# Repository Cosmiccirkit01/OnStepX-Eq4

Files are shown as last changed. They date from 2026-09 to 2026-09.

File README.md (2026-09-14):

# EQ4 to GoTo Mount Conversion using OnStepX

Converting a manual Skywatcher EQ4 equatorial mount into a fully computerized GoTo mount using [OnStepX](https://github.com/hjd1964/OnStepX) firmware on an ESP32 microcontroller.

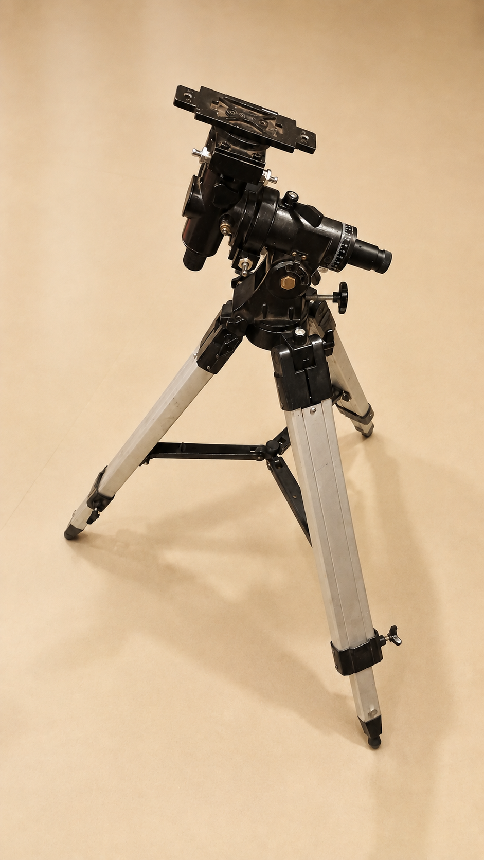
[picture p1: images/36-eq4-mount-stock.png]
Stock EQ4 mount


## Overview

[OnStepX](https://github.com/hjd1964/OnStepX) is an open-source, computerized GoTo controller for telescope mounts, built around stepper motors. It supports both Equatorial and Alt/Az mounts and runs on a range of microcontrollers (ESP32, STM32 Blue Pill/Black Pill, Fysetc boards, Teensy, etc.).

This project documents converting a stock **EQ4 equatorial mount** into a GoTo mount using an **ESP32**, custom-built stepper driver electronics, and a 3D-printed mount for the electronics. It covers everything from flashing the firmware to designing a custom PCB to machining brackets for motors that the mount was never designed to hold.

> **Note:** This is a personal build log, not an official OnStepX guide. Some steps (such as pin assignments and gear ratios) are specific to this hardware combination and may need to be adapted for other mounts or driver boards.

## Table of Contents

- [Bill of Materials](#bill-of-materials)
- [Step 1: Flashing OnStepX Firmware to the ESP32](#step-1-flashing-onstepx-firmware-to-the-esp32)
- [Step 2: Connecting the ESP32 to the OnStep Controller App](#step-2-connecting-the-esp32-to-the-onstep-controller-app)
- [Step 3: Choosing a Motor Driver and Setting Vref](#step-3-choosing-a-motor-driver-and-setting-vref)
- [Step 4: Breadboard Testing](#step-4-breadboard-testing)
- [Step 5: Designing a Custom PCB](#step-5-designing-a-custom-pcb)
- [Step 6: Firmware Configuration](#step-6-firmware-configuration)
- [Step 7: Setting Up the Web Server Plugin](#step-7-setting-up-the-web-server-plugin)
- [Step 8: Servicing the Mount and Fitting Motor Brackets](#step-8-servicing-the-mount-and-fitting-motor-brackets)
- [Safety Notes](#safety-notes)
- [Credits](#credits)
- [Additional Photos & Videos](#additional-photos--videos)
- [Status / Next Steps](#status--next-steps)
- [Note](#Note)

## Bill of Materials

| Component | Notes | Link |
|---|---|---|
| Digital Multimeter | For voltage/continuity checks | [Link](https://robu.in/product/digital-multimeter-small-yellow-color-lcd-ac-dc-measuring-voltage-current/) |
| Breadboard (840 tie points) | For initial circuit testing | [Link](https://robu.in/product/breadboard-840-tie-points-solderless-diy-project-circuit-test-breadboard) |
| ESP32 (ESP-WROOM-32) | Main microcontroller | [Link](https://robu.in/product/esp-wroom-32-esp32-wifi-bt-ble-mcu-module) |
| NEMA17 Stepper Motor | 200 steps/rev, one per axis | [Link](https://robu.in/product/nema17-pr42hs40-1204af-02-4-2kg-cm-stepper-motor-d-type-shaft) |
| DRV8825 Motor Driver | One per axis (see [driver comparison](#step-3-choosing-a-motor-driver-and-setting-vref)) | [Link](https://robu.in/product/drv8825-stepper-motor-driver-with-aluminum-heat-sink) |
| Electrolytic Capacitor (100µF, 50V) | Protects driver from voltage spikes | [Link](https://robu.in/product/100uf-50v-20-chip-type-aluminum-electrolytic-capacitor-smt-pack-of-5) |
| Jumper Cables (M2M) | Breadboard wiring | [Link](https://robu.in/product/male-to-male-jumper-wires-40pcs-20cm) |
| Power Source: 12V, 2A (or 12V, 5A) | 2A is sufficient for testing; upgrade to 5A if needed | [2A](https://robu.in/product/ntl-orange-12vol-2amp-3pin-wall-mount-type-adapter) · [5A](https://robu.in/product/orange-ac-100-240v-to-dc-12v-5a-60w-power-adapter/) |
| Active Buzzer | Status indication | [Link](https://robu.in/product/5v-active-electromagnetic-buzzer-pack-of-5) |
| Step-Down Buck Converter | Steps 12V down to 5V for the driver FLT pin | [Link](https://robu.in/product/mini-360-step-down-buck-converter-power-module) |
| 4-Pin Aviation Connectors | Detachable motor/power connections | [Link](https://robu.in/product/gx-16-4-pin-metal-aviation-plug-male-and-female-panel-connector/) |
| L-shaped brackets (NEMA17) | Mounting motors to the axes | [Link](https://roboticsdna.in/product/bracket-for-nema-17-stepper-motor/) |
| GT2 Pulleys (60T & 12T) | 5:1 gear ratio | [60T](https://robu.in/product/gt2-6mm-belt-width-60-teeth-5mm-bore-aluminium-timing-pulley/) · [12T](https://thinkrobotics.com/products/gt2-timing-pulley?_pos=1&_sid=6cd249838&_ss=r) |
| GT2 Timing Belt | Closed-loop, 180mm | [Link](https://www.superbtech.in/product/180mm-gt2-closed-loop-rubber-timing-belt-6mm-width-for-3d-printer-cnc) |

---

## Step 1: Flashing OnStepX Firmware to the ESP32

1. Download the OnStepX firmware from the [official GitHub repository](https://github.com/hjd1964/OnStepX) — use the **`main`** branch for the latest configuration. Latest version for this build: **10.28**.

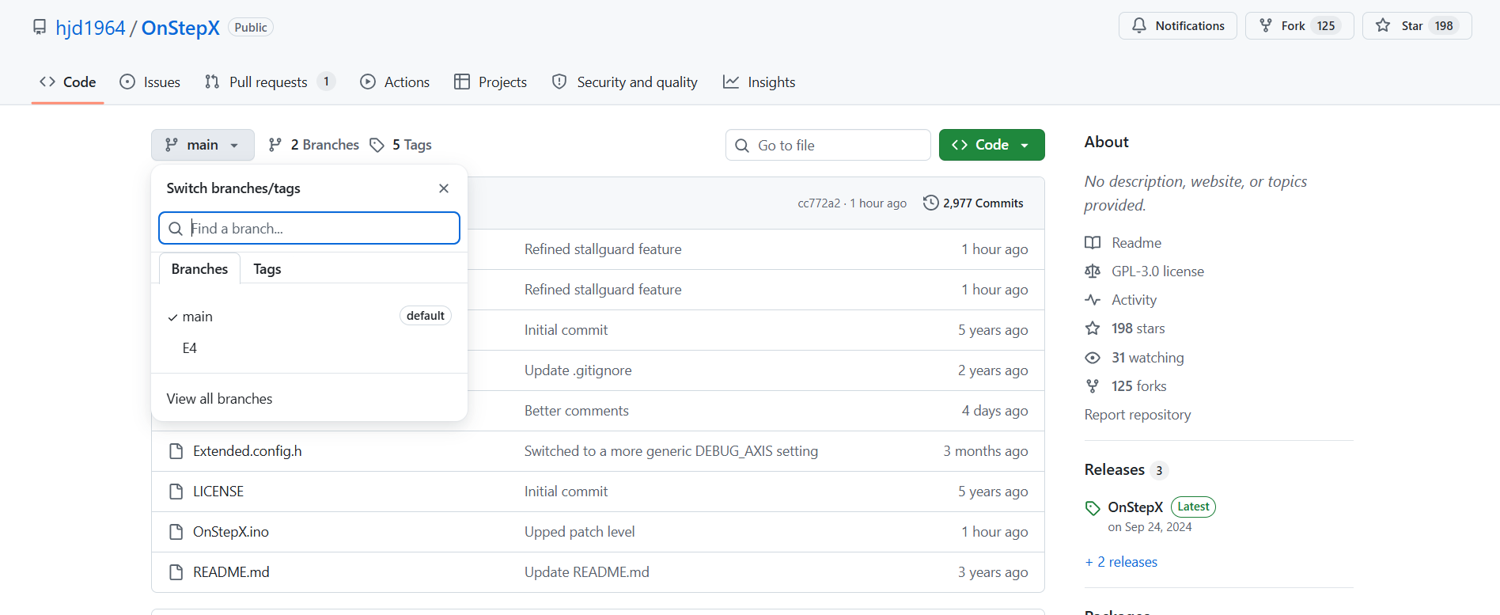
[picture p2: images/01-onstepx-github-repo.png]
OnStepX GitHub repository
   
   *Credits: [hjd1964](https://github.com/hjd1964)*

2. Unzip the downloaded file (it extracts as `OnStepX-main`) and rename the folder to **`OnStepX`**.

3. Open the folder — it should contain the following files:

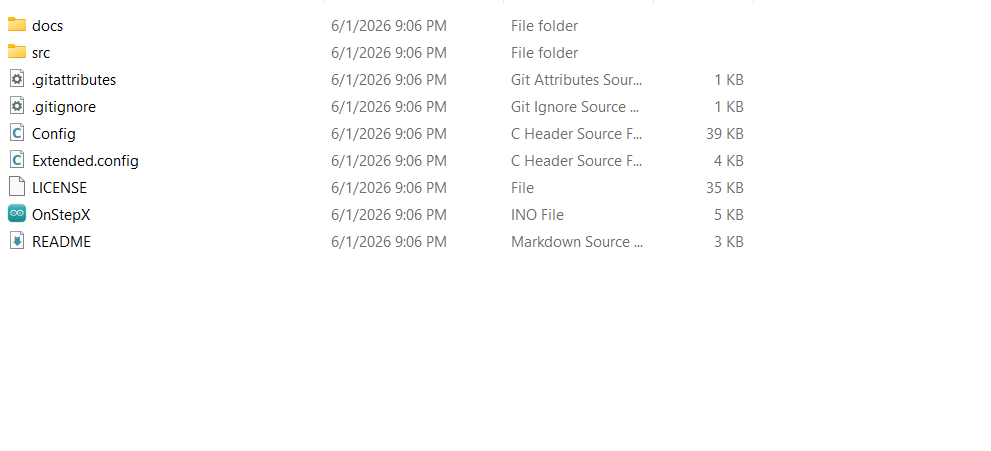
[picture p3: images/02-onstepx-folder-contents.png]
OnStepX folder contents
   

4. Open the **`OnStepX.ino`** file. This launches Arduino IDE along with the `Config.h` and `Extended.config.h` files alongside it.

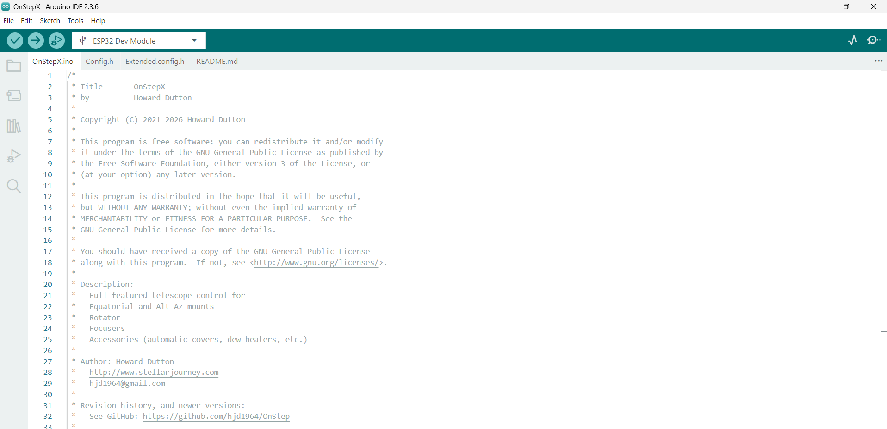
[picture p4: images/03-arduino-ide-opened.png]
Arduino IDE with OnStepX project open
   

   If you don't have Arduino IDE installed, download it from the [official website](https://arduino-ide.org/).

5. **Install the ESP32 USB driver.** The ESP32 dev board uses a CP210x USB-to-UART chip, which needs an external driver on most systems. Follow [this driver installation guide](https://github.com/AnnemHarshaVardhan1811/Install-ESP32-ESP8266-USB-Drivers-CP210x-USB-to-UART-Bridge-Windows-PC-) if needed.

6. **Add the ESP32 board package to Arduino IDE:**
   - Go to **File**

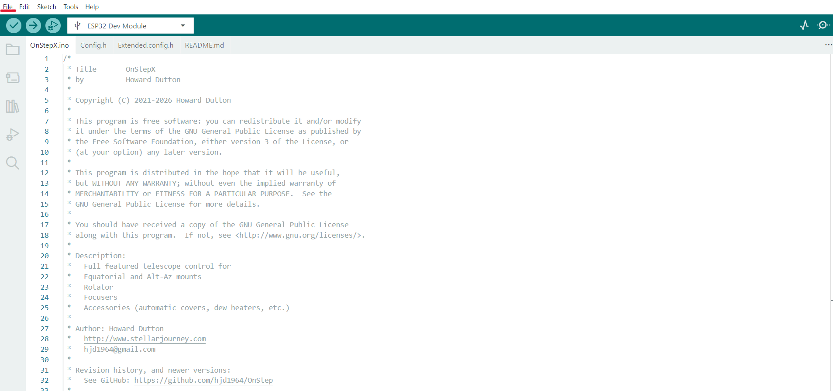
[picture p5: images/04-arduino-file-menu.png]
Arduino IDE File menu
     

   - Go to **Preferences**

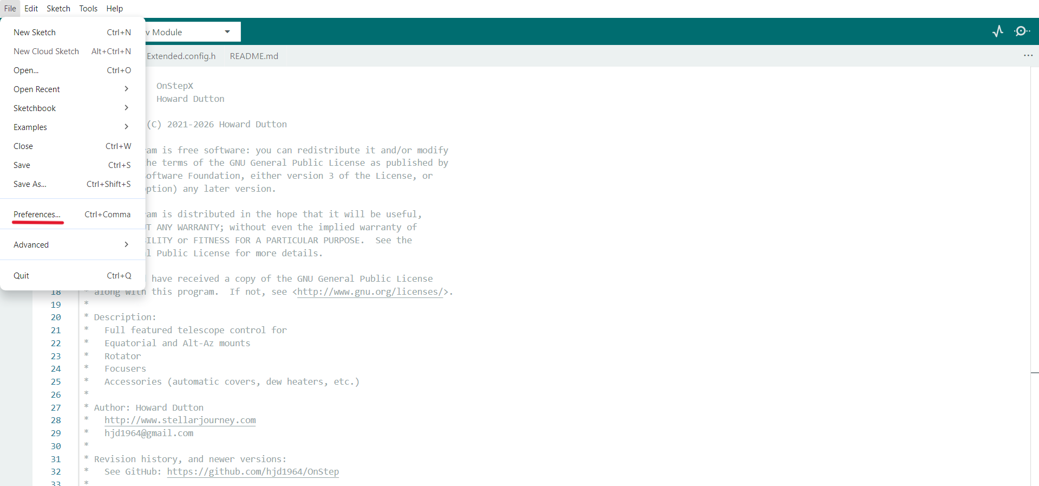
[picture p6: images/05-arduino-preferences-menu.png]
Preferences menu
     

   - In the Preferences window, paste the following URL into **Additional Boards Manager URLs**, then click **OK**:

     ```
     https://raw.githubusercontent.com/espressif/arduino-esp32/gh-pages/package_esp32_index.json
     ```

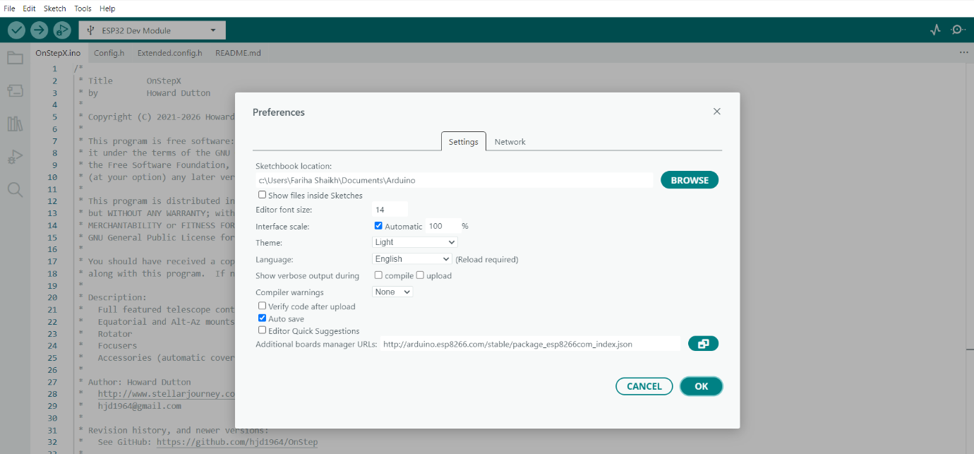
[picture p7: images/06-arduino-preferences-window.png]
Preferences window
     

7. **Select the board and port.** Click the board/port dropdown and choose **"Select other board and port"**.

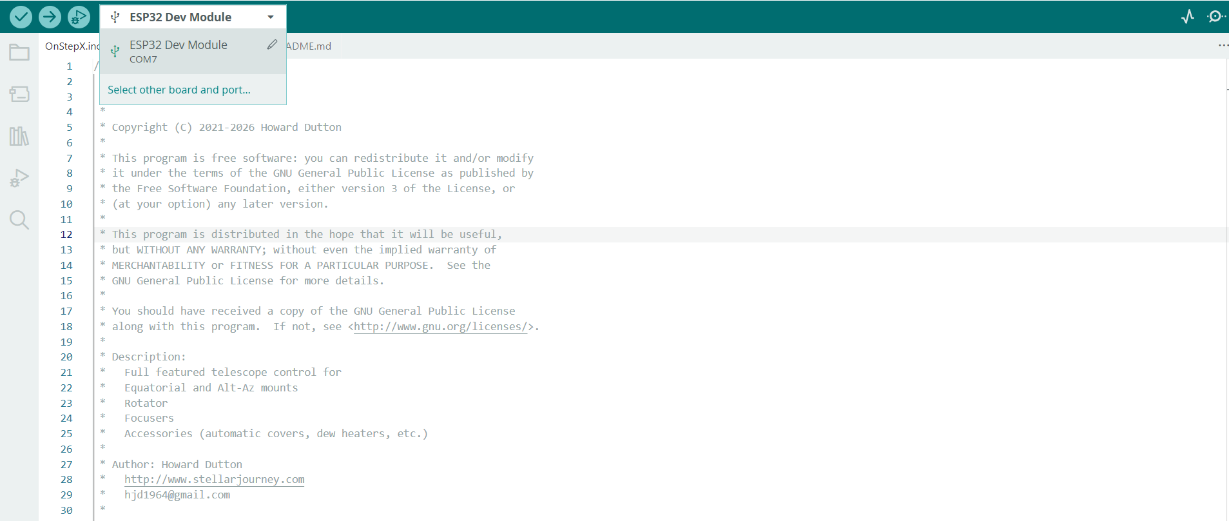
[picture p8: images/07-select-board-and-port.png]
Select board and port
   

   Select your ESP32 variant and the COM port it's connected to (in this build: **ESP32 Dev Module** on **COM7**).

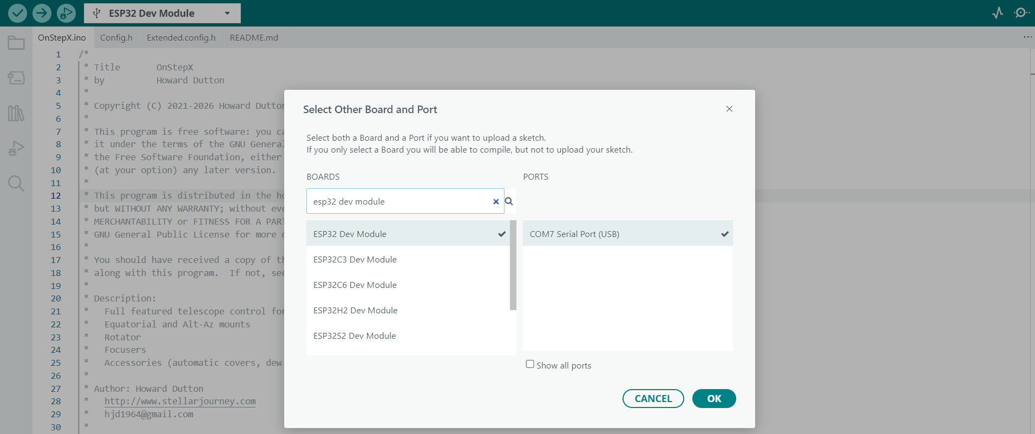
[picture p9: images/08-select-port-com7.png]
Select port COM7
   

8. Click **Upload**.

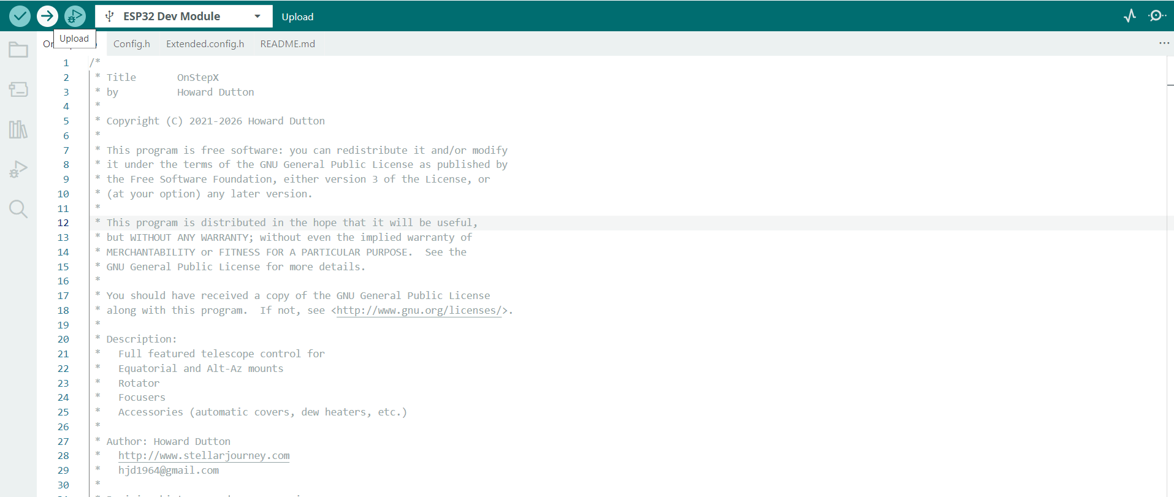
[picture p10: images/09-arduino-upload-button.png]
Upload button
   

9. **Verify the flash succeeded:** open the Serial Monitor, type `#GVP:`, and press Enter. A response of `Onstep` confirms the firmware flashed correctly.

## Step 2: Connecting the ESP32 to the OnStep Controller App

1. Once flashed, the ESP32 broadcasts its own Wi-Fi access point named **`OnStepX`**. Connect to it — the password is **`password`**.

2. Install **OnStep Controller2** from the Play Store and open it.

3. When prompted *"Would you like to create a new one now?"*, tap **Yes**.

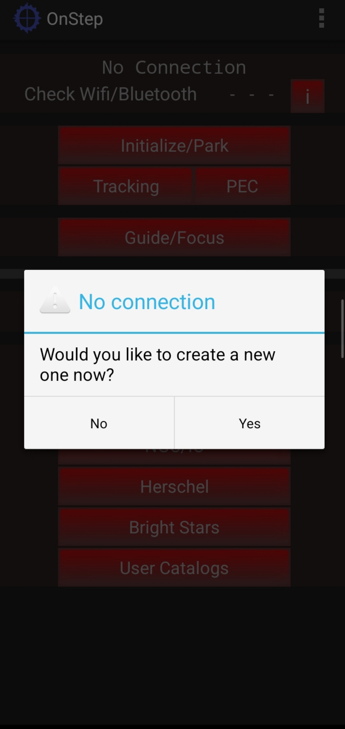
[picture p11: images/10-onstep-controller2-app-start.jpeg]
OnStep Controller2 app start screen
   

4. On the connection screen, enter the IP address **`192.168.0.1`** and tap **Accept**.

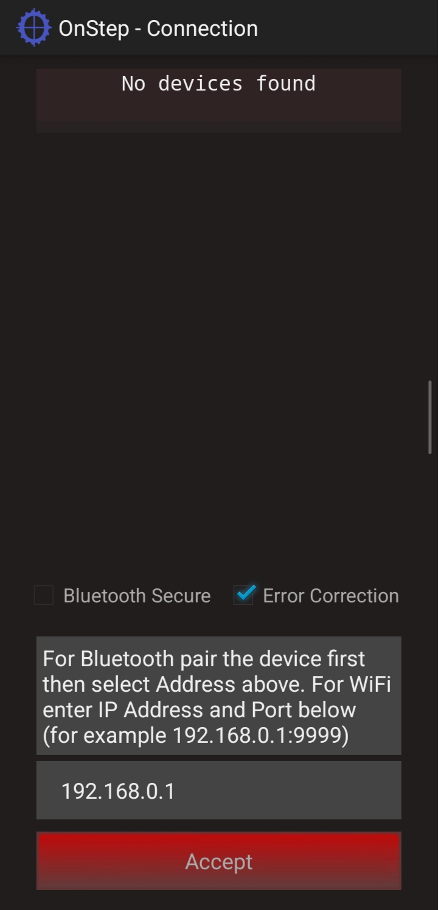
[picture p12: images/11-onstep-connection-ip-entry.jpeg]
Entering the connection IP
   

5. Wait a few seconds for the app to connect to the mount.

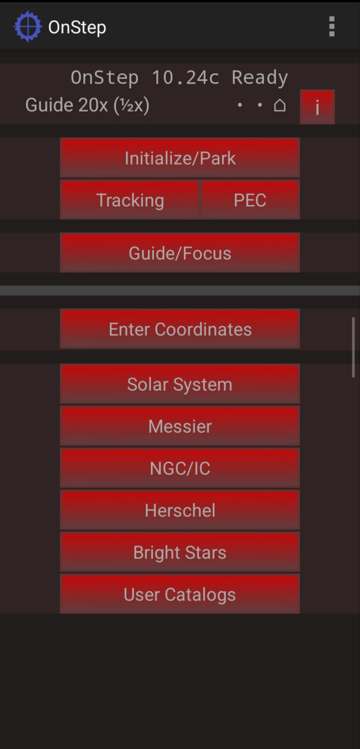
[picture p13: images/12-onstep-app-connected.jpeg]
Connected to the mount
   

6. Tap the **three-dot menu** (top right) → **Observing Sites**, and enter your local **Latitude**, **Longitude**, and **UTC Offset**. Tap **Upload**, then return to the main menu.

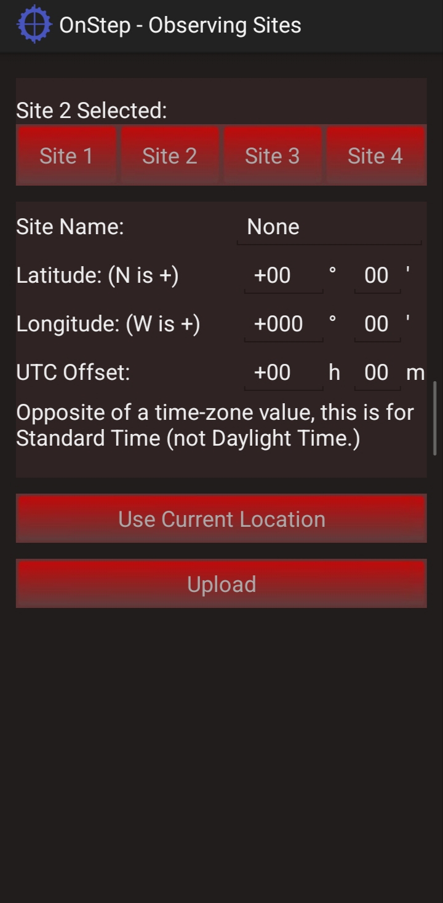
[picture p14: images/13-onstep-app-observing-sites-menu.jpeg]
Observing Sites menu
   

7. From the main menu, go to **Initialize/Park**. This is where most mount actions (park, unpark, home, goto) happen.

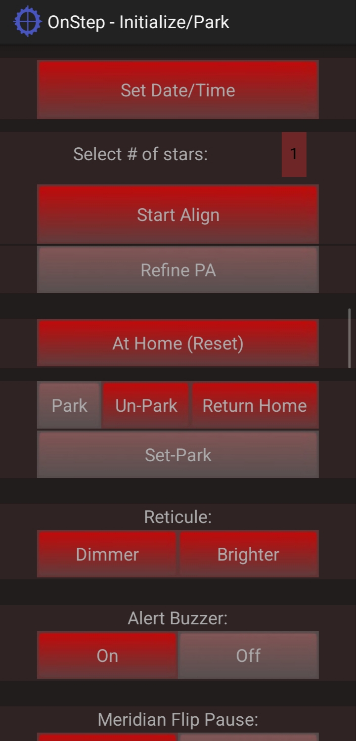
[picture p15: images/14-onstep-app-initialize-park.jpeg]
Initialize/Park screen
   

   > **Important:** Tap **Set Date/Time** before unparking. If this step is skipped, the mount won't accept any further commands.

Alternatively, the [Triton GoTo App](https://tritongoto.com/download) is worth trying — it includes a built-in planetarium view and has a more intuitive setup flow than the stock OnStep app.

## Step 3: Choosing a Motor Driver and Setting Vref

### A4988 vs. DRV8825

A NEMA17 stepper motor takes **200 full steps per revolution** (1.8° per step). Microstepping divides each full step into smaller increments for finer resolution:

| Driver | Max microsteps | Degrees per microstep | Steps per revolution |
|---|---|---|---|
| A4988 | 16 | 1.8° / 16 = 0.1125° | 3,200 |
| DRV8825 | 32 | 1.8° / 32 = 0.05625° | 6,400 |

Finer steps mean smoother, more precise tracking — important for accurately locating objects in the sky. This build started with an A4988 for initial testing, then upgraded to the **DRV8825** for higher resolution (and for a second reason covered in [Step 5](#step-5-designing-a-custom-pcb)).

### Setting the reference voltage (Vref)

Vref limits the current the driver delivers to the motor, protecting both the driver and the motor from damage.

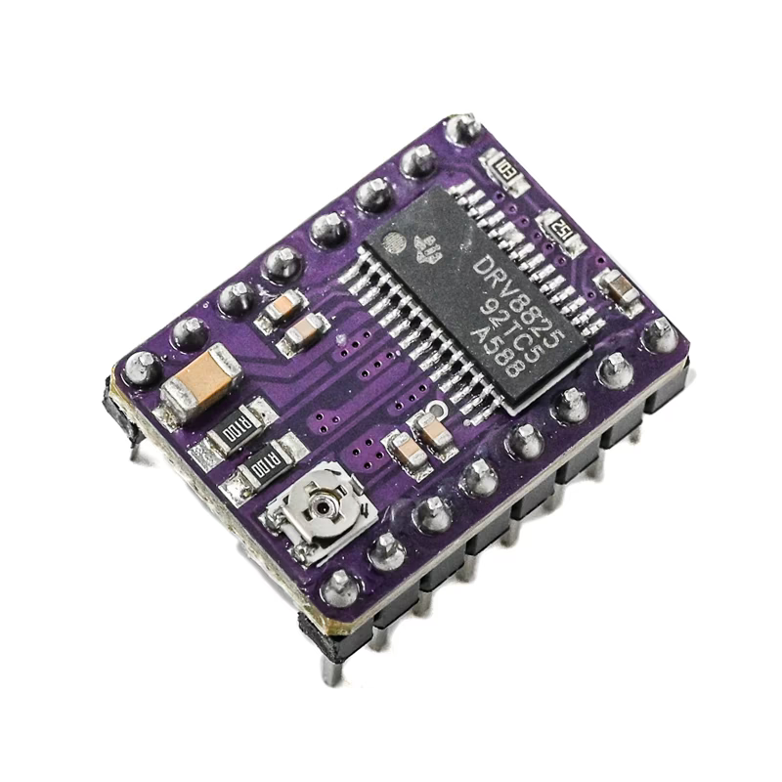
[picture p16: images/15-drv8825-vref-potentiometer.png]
DRV8825 Vref potentiometer


Vref is set using the small potentiometer on the driver board (turn carefully with a small screwdriver — it's easy to damage).

**Formula:**

```
Vref = Imax / 2
```

For the NEMA17 motor used here, `Imax = 1.2A` per phase:

```
Vref = 1.2 / 2 = 0.6V
```

For a safety margin, this build used **10% less**:

```
Vref = 0.5V
```

**To measure and set it:** power the driver with +5V (connect GND to GND, and FLT to +5V — the pinout may differ slightly by board, but this method works regardless). With the multimeter's red probe on the potentiometer and black probe on GND, adjust until the reading matches your target Vref.

If you run into trouble, [this YouTube tutorial](https://youtu.be/wcLeXXATCR4?si=PvDwpPcGoeFdWh77) walks through the process on an A4988 — the same steps apply to the DRV8825. The main difference is that the DRV8825 has a **FLT** pin where the A4988 has **VDD**. See the [DRV8825 connection notes](https://robu-prod-media.s3.ap-south-1.amazonaws.com/uploads/2017/12/Stepper-Motor-Driver-DRV8825-Power-Dissipitation-Considerations.pdf) for reference.

Datasheets: [DRV8825](https://robu-prod-media.s3.ap-south-1.amazonaws.com/uploads/2017/12/drv8825.pdf) · [A4988](https://robu-prod-media.s3.ap-south-1.amazonaws.com/uploads/2015/12/pololu_a4988-1.pdf)

## Step 4: Breadboard Testing

1. **Identify motor coil pairs.** On this motor, Red/Blue was Coil 1 and Green/Black was Coil 2 — verify yours with a multimeter or the tutorial linked above, since wire colors vary by motor.

2. **Find your ESP32 pinmap.** Inside the OnStepX folder, go to:

   ```
   OnStepX > src > pinmaps
   ```

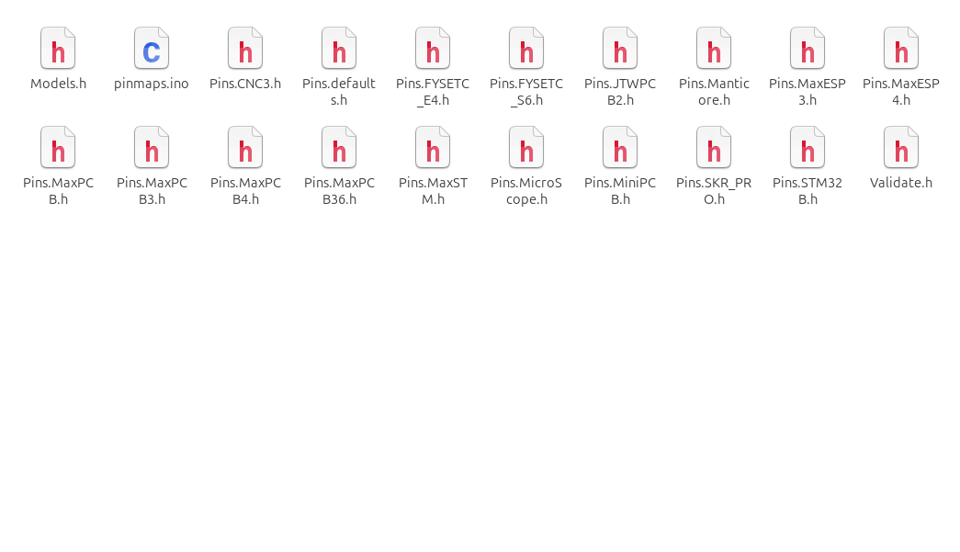
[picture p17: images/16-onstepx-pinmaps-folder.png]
Pinmaps folder
   

   Select the file matching your MCU — this build used **`Pins.MaxESP3.h`**.

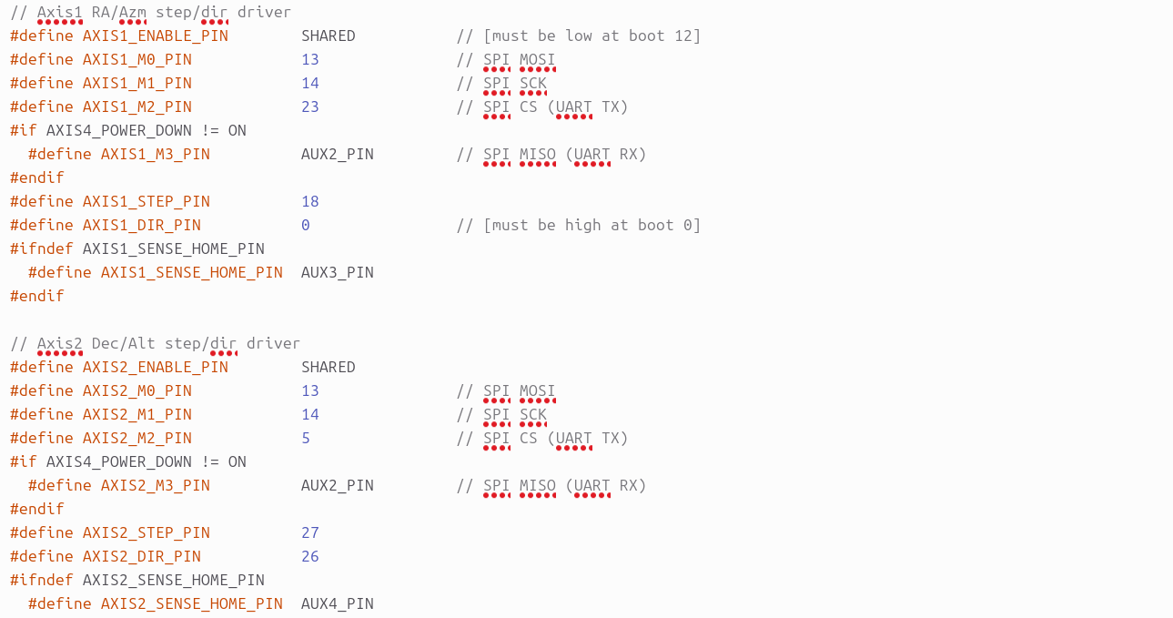
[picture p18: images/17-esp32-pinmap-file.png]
ESP32 pinmap file open
   

   Scroll to the **AXIS1** / **AXIS2** definitions and wire accordingly. Optional buzzer/LED status pins can also be added here.

3. **Wire the power stage.** Connect the 100µF electrolytic capacitor as shown in the [wiring video](https://youtu.be/wcLeXXATCR4?si=PvDwpPcGoeFdWh77) above. `VMOT` connects to **+12V**, and `FLT` connects to **+5V** — ideally from a step-down buck converter rather than the ESP32's own 5V rail.

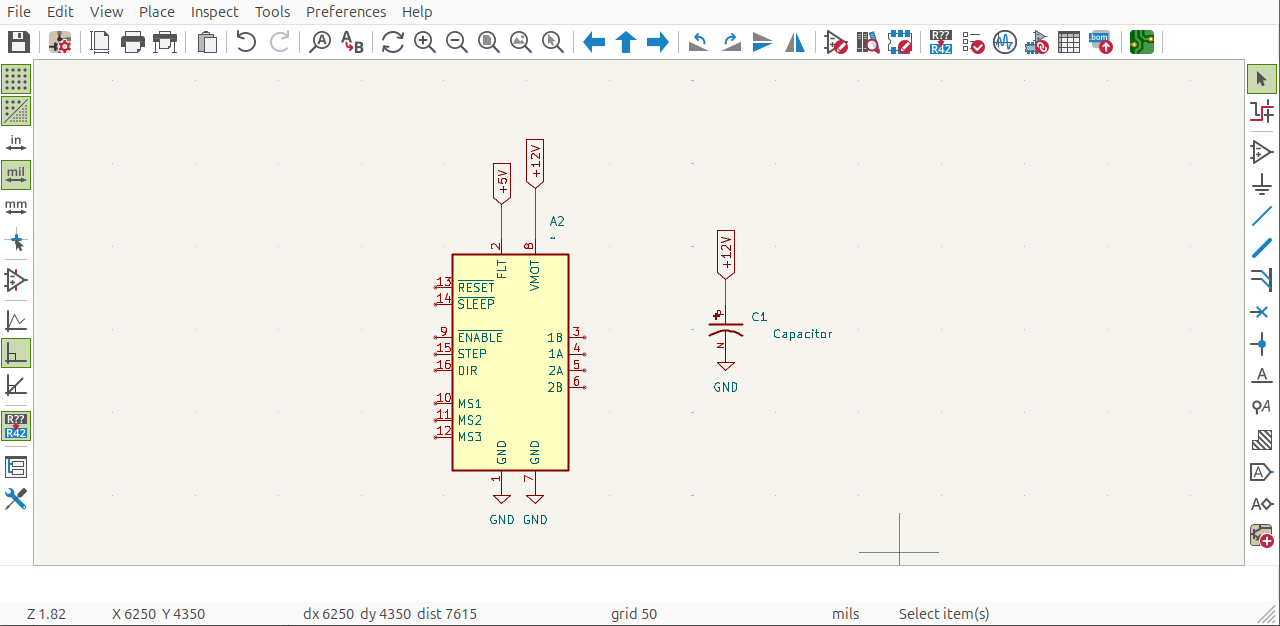
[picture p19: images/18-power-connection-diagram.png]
Power connection diagram
   

   This build used a **12V, 2A** supply.

4. **Test one axis at a time.** Wire and test **Axis 1 (RA)** first. Power on, connect the ESP32 via USB, open the OnStep app, and go to **Guide/Focus** to manually jog the motor and confirm it moves correctly in both directions.

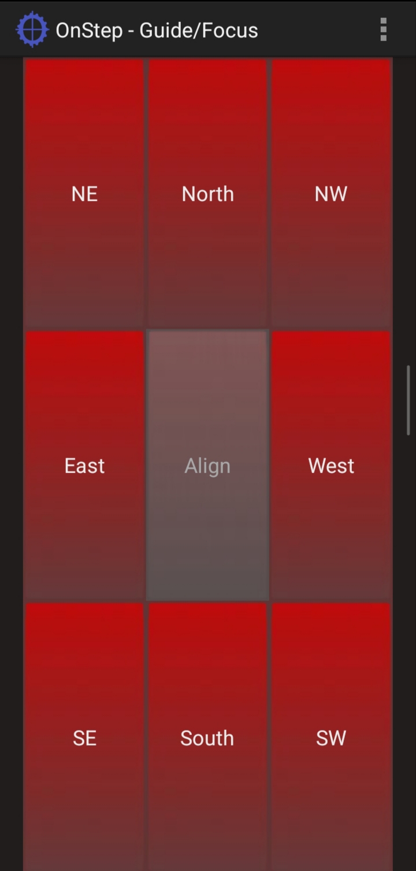
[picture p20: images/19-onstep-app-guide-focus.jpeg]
Guide/Focus screen
   

   Once Axis 1 works, repeat the same wiring and test process for **Axis 2 (Dec)**.

5. **Run both axes together** on the breadboard before moving to a permanent circuit.

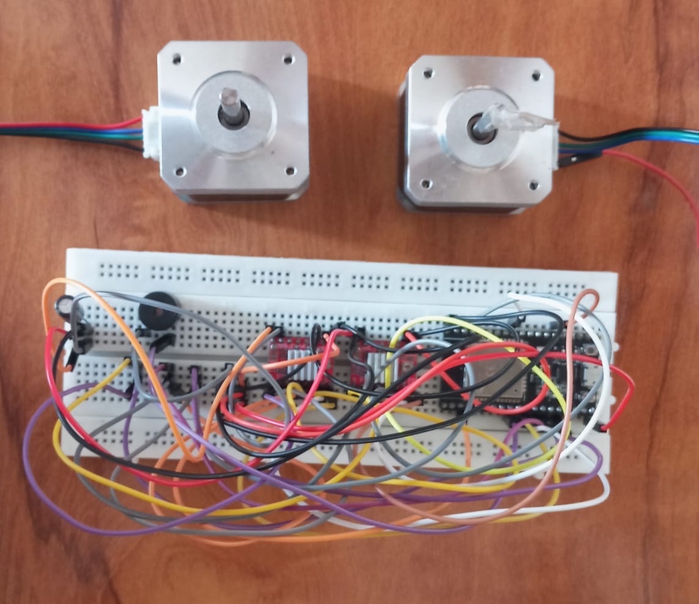
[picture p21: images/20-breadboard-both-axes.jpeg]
Breadboard circuit with both axes wired
   

   > If motors behave erratically, check that the capacitor is installed and that the power supply is adequate. And if problems still persist there may be a fault with wiring itself. 

## Step 5: Designing a Custom PCB

The first PCB used for this build had an internal short at the 12V input hole, which cascaded into shorts across nearby resistors and capacitors — making the board unusable.

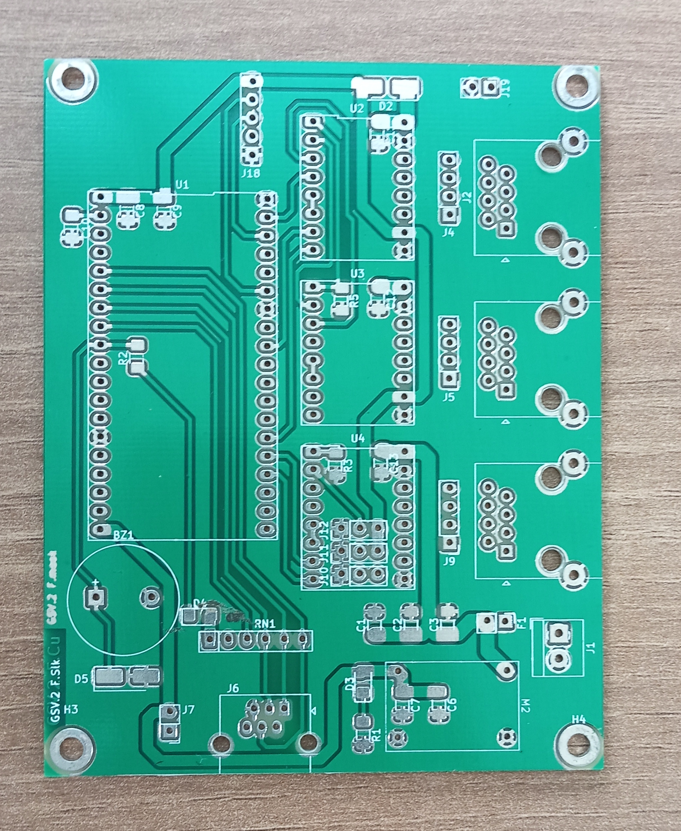
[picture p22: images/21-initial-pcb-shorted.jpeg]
Initial PCB with internal short


**What is a short?** A short circuit is an unintended low-resistance connection between two points (+12V and GND). This allows excessive current to flow, which can overheat and damage the circuit. A multimeter's continuity mode (which beeps when it detects a connection) is a fast way to check for shorts before powering anything on.

Since the original board was unrepairable, a **custom PCB** was designed from scratch in [KiCad](https://www.kicad.org/download/).

1. **Schematic** — includes the ESP32, A4988/DRV8825, and buck converter. Footprints for the ESP32 and driver were available online; the buck converter's footprint was custom-made by measuring the physical board.

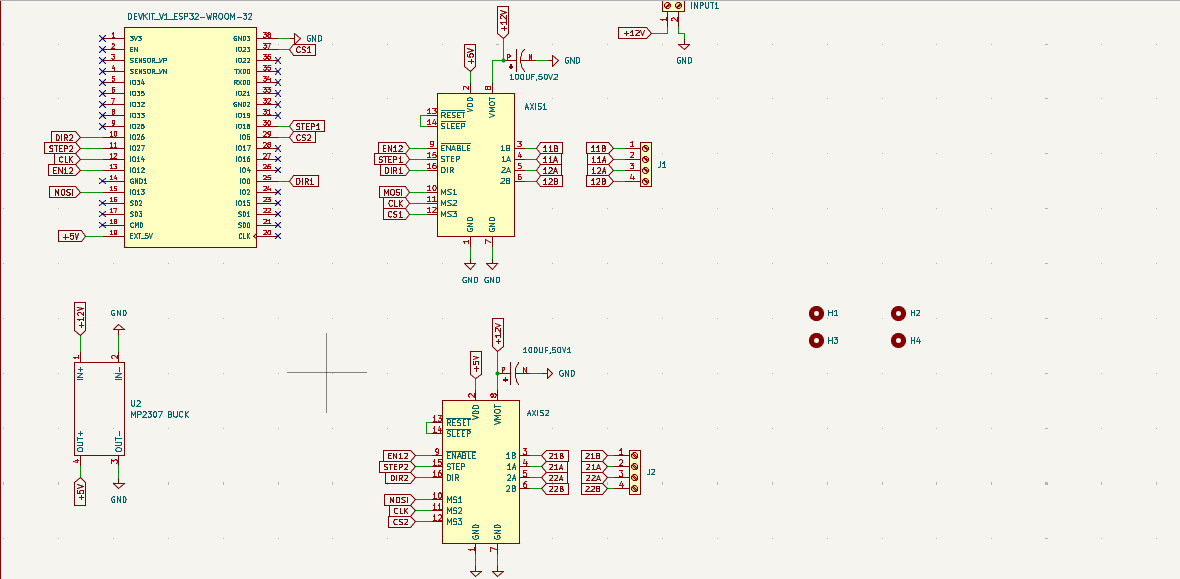
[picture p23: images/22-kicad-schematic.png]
KiCad schematic
   

2. **PCB layout** — routed after the schematic was finalized.

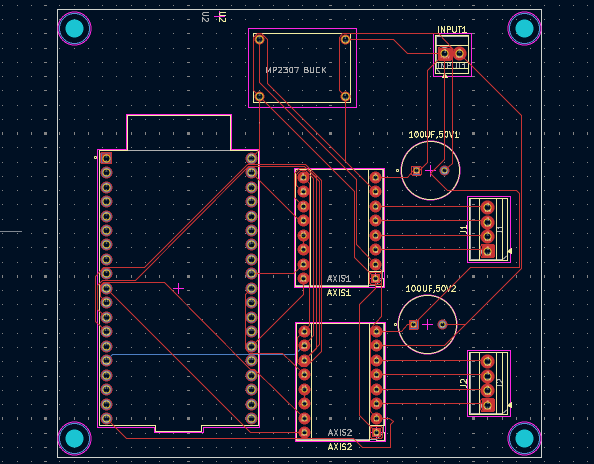
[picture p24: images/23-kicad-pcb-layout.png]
KiCad PCB layout
   

3. **3D preview** — used to sanity-check the layout before fabrication.

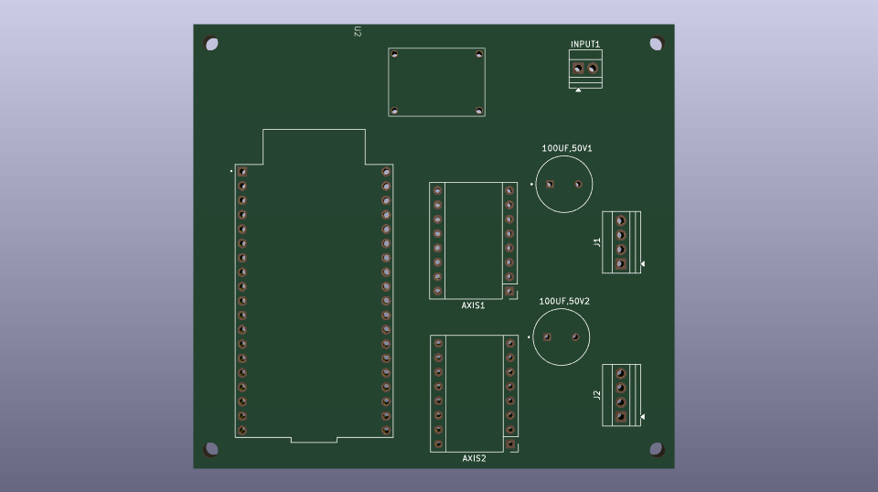
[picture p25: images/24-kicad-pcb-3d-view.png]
KiCad 3D PCB view
   

4. **Generate Gerber files:** `File > Fabrication Outputs > Gerbers (.gbr)`. Run **DRC** first to catch errors, then **Plot**, then **Save**.

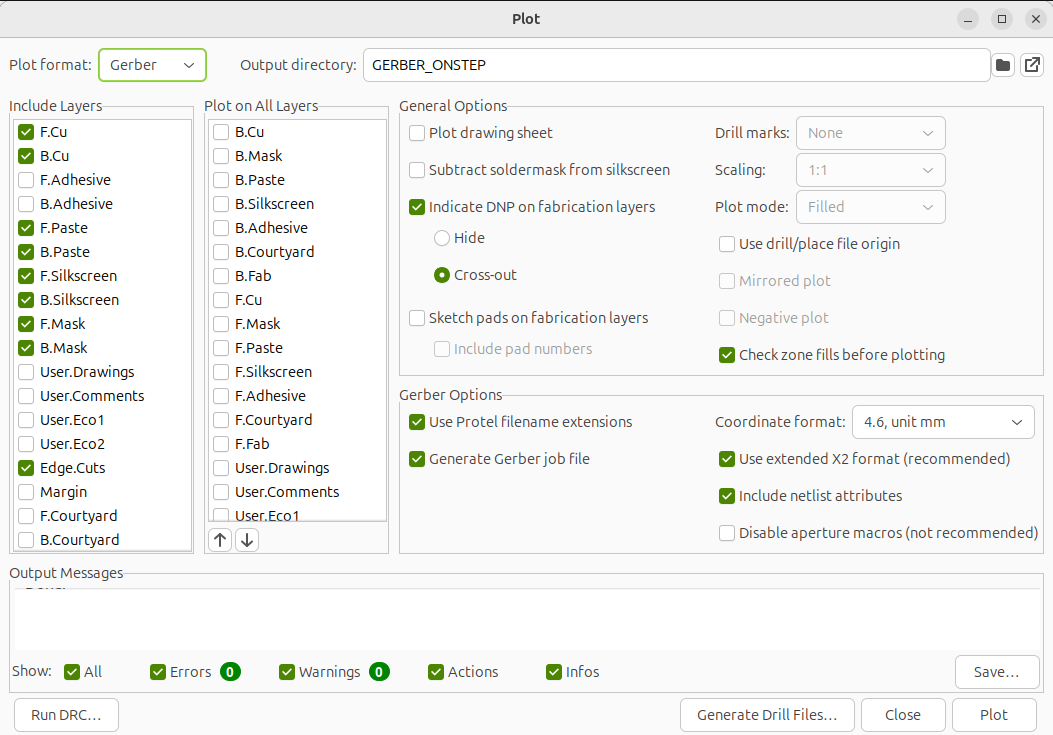
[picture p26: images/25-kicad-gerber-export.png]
Gerber export screen
   

5. **Fabrication and assembly:**

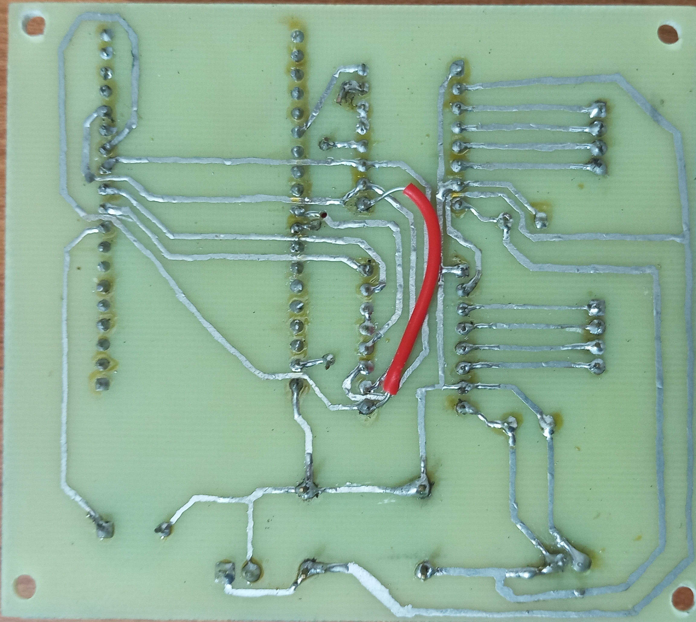
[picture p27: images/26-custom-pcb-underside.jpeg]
Fabricated PCB underside
   

   This is a **single-sided** PCB — the underside shows the routed copper tracks. Three connections that couldn't be routed on one layer were completed with single-strand jumper wire.

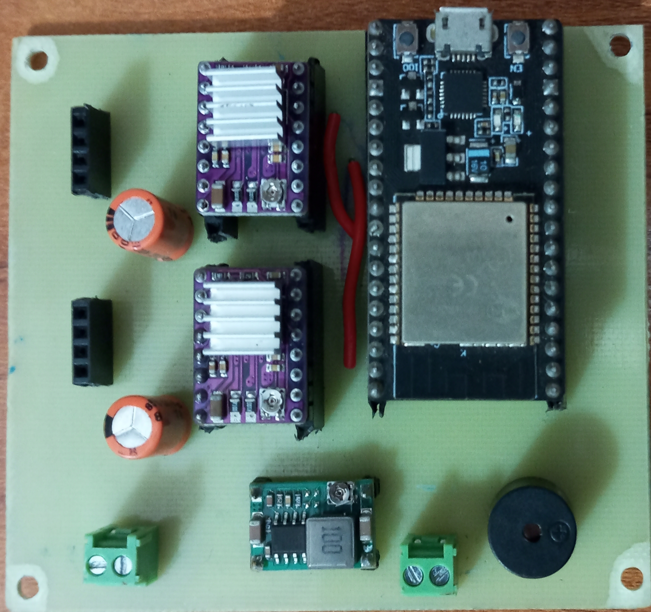
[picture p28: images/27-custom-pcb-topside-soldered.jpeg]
Fabricated PCB, populated, topside
   

   Populated components: ESP32, DRV8825, step-down buck converter, active buzzer, and the 100µF electrolytic capacitor. Motor and power connectors are separate.

6. **Enclosure:** a custom case was 3D-printed to house the finished board.

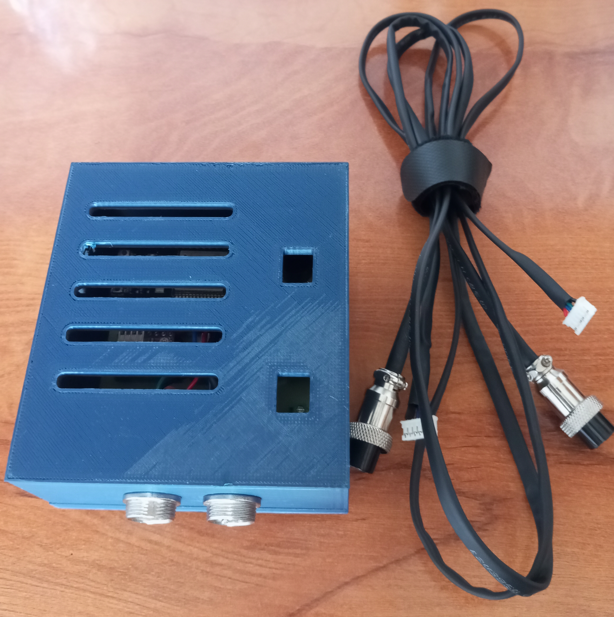
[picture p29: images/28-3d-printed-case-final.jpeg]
3D-printed case, finished electronics
   

Motor driver connections to the NEMA17 use the motor's original connectors, soldered to 1-meter aviation connectors — long enough to avoid tension or interference around the mount.

## Step 6: Firmware Configuration

This is the step that matches the firmware's electrical and mechanical parameters to your specific hardware — arguably as important as the wiring itself.

1. Go to the [OnStep Configuration Generator](http://o.baheyeldin.com:1111/).

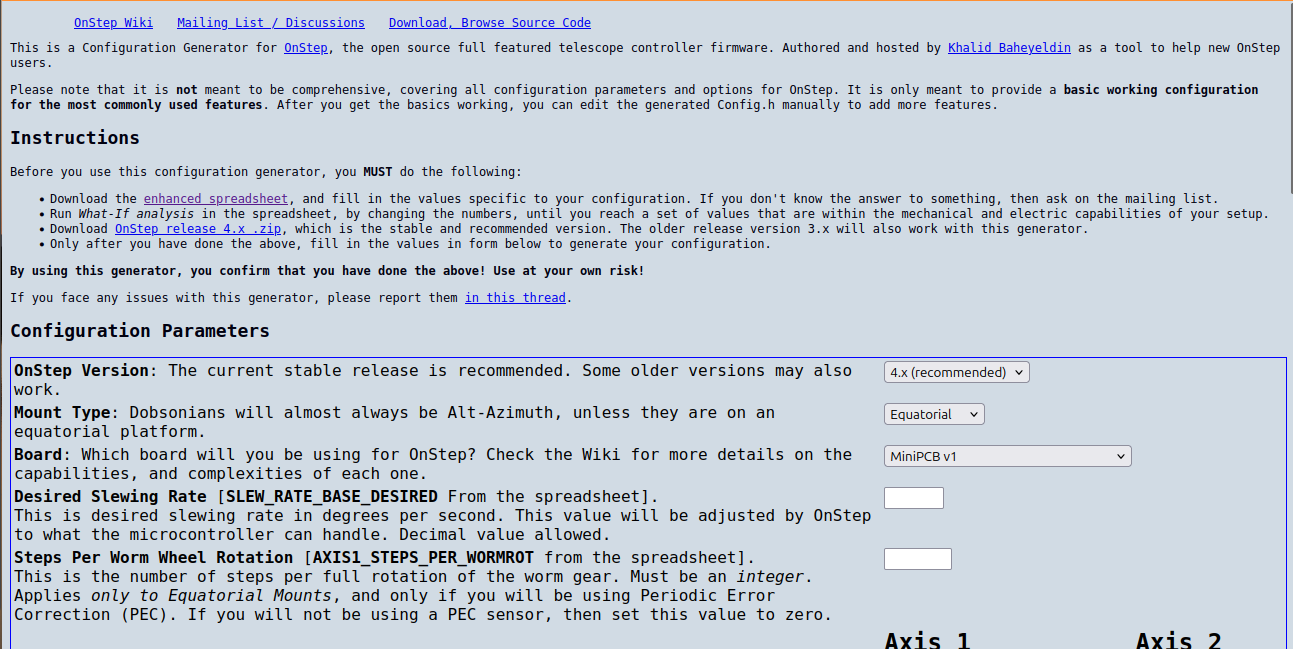
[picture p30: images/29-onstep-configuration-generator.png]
Configuration generator homepage
   
   *Credits: [Khalid Baheyeldin](https://www.progressiveautomations.com/)*

2. Download the **enhanced spreadsheet** it links to.

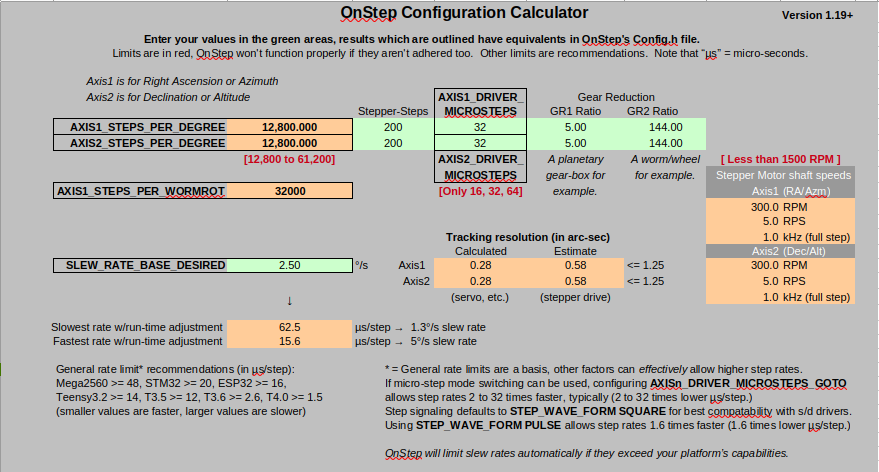
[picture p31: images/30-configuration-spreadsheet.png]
Configuration spreadsheet
   

   This spreadsheet calculates the correct settings for your driver and gearing. Key fields:

   | Field | What it means | Value used in this build |
   |---|---|---|
   | **Stepper Steps** | Full steps per motor revolution (check your motor's datasheet) | 200 (NEMA17) |
   | **AXIS1/2_DRIVER_MICROSTEPS** | Maximum microsteps your driver supports | 32 (DRV8825) |
   | **GR2 Ratio** | Number of teeth on the mount's worm wheel | 144 (EQ4) |
   | **GR1 Ratio** | Pulley gear ratio (large pulley teeth ÷ small pulley teeth) | 5 (60T / 12T) |

3. **Checking if your gear ratio is sufficient:**

   ```
   Steps per degree = (Stepper Steps × Microsteps × GR1 × GR2) / 360
   ```

   With a DRV8825 (32 microsteps) and GR1 = 5:

   ```
   (200 × 32 × 5 × 144) / 360 = 12,800 steps/degree
   ```

   With an A4988 (16 microsteps), a **higher GR1 (≥10)** is needed to hit a comparable resolution:

   ```
   (200 × 16 × 10 × 144) / 360 = 12,800 steps/degree
   ```

   Higher steps-per-degree means finer, more precise tracking resolution. Choose your driver's microstep setting and GR1 ratio together based on the resolution you need.

4. Fill in only the fields relevant to your hardware in the spreadsheet, leaving the rest at default, then return to the generator site and click **Generate**. This produces a `Config.h` file — copy it into your `OnStepX` folder (where the `.ino` file lives), replacing the existing `Config.h` when prompted.

## Step 7: Setting Up the Web Server Plugin

OnStepX supports an optional web-based control interface via a plugin.

1. Download the plugin from the [OnStepX-Plugins repository](https://github.com/hjd1964/OnStepX-Plugins/tree/v1.0a).

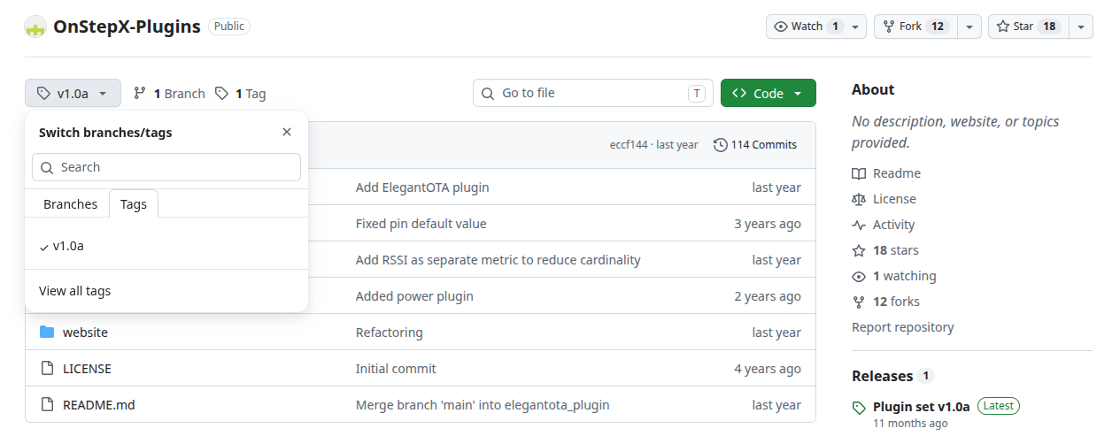
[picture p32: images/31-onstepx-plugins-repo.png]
OnStepX-Plugins repository
   
   *Credits: [hjd1964](https://github.com/hjd1964)*

   > This build uses tag **v1.0a** specifically — the `main` branch had errors at the time of writing.

2. Extract the download and copy the `website` folder into:

   ```
   OnStepX > src > plugins
   ```

3. Open **`Plugins.config.h`** and add:

   ```cpp
   #define PLUGIN1 website
   #include "website/Website.h"
   ```

4. In **`Config.h`**, just below the `PINMAPS` section under **SERIAL PORT COMMAND CHANNELS**, add:

   ```cpp
   #define SERIAL_RADIO WIFI_ACCESS_POINT
   ```

5. In **`Extended.config.h`**, near the end of the file, add:

   ```cpp
   #define SERIAL_IP_MODE WIFI_ACCESS_POINT
   #define WEB_SERVER on
   ```

6. Save both files and reflash the ESP32. Connect to its Wi-Fi network, then open a browser to **`192.168.0.1`** to reach the OnStepX web interface.

**Web interface screens:**

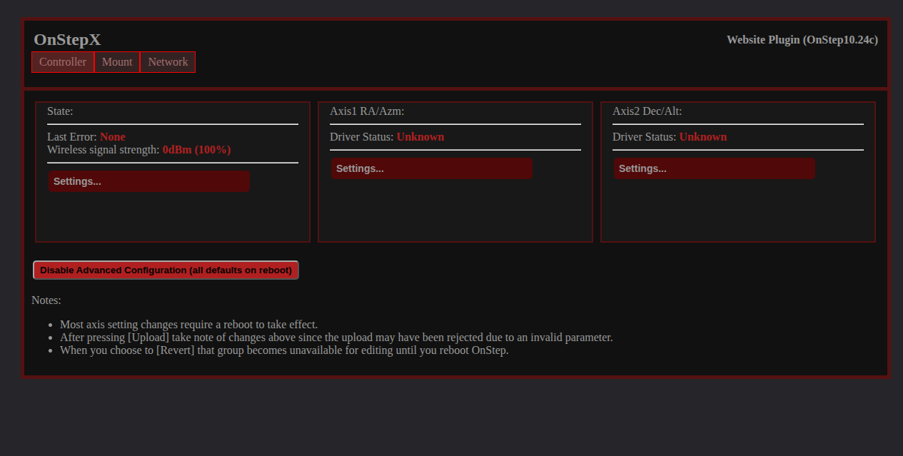
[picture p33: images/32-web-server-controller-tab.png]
Web server — Controller tab


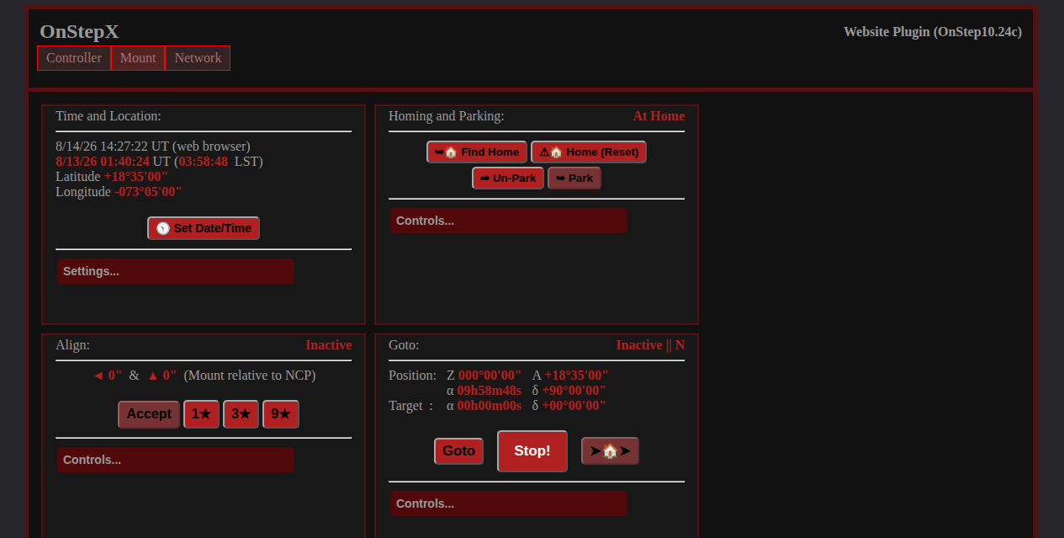
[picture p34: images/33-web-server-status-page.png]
Web server — status page


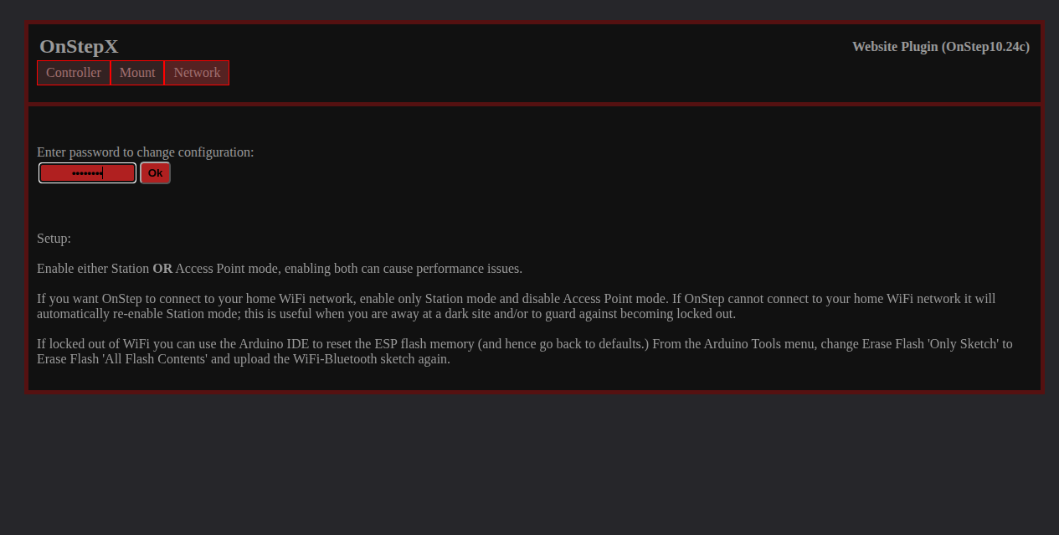
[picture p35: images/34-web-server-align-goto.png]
Web server — align and goto controls


Opening the **Network** tab prompts for a password — again, it's **`password`** by default.

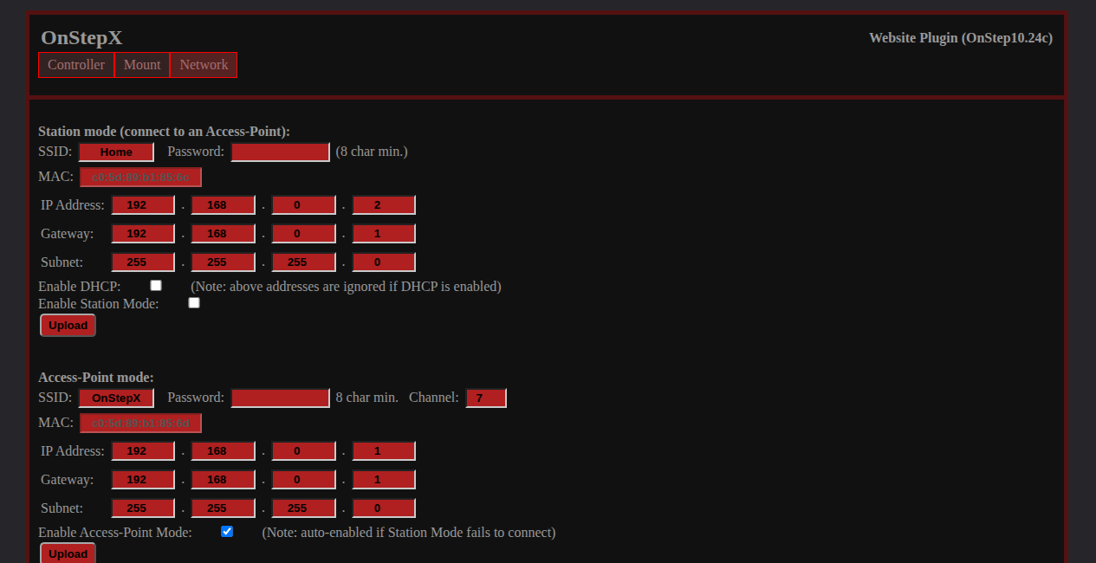
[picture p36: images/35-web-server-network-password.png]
Web server — network password prompt


## Step 8: Servicing the Mount and Fitting Motor Brackets

This build is based on a stock **EQ4** mount.

Before adding any electronics, the mount was fully disassembled and inspected:

- Checked all parts for wear.
- Cleaned old grease buildup off the worm wheel and worm shaft.
- Re-greased the gears for smooth movement.
- Reassembled and adjusted the worm shaft tension screws until it turned with even, moderate resistance (neither too loose nor too tight).
- Verified smooth manual movement before adding any motorized components.

### Fitting motor brackets

Some mounts — like the **Explore Scientific EXOS2** with a OnStep kit — have screw holes purpose-built for motor brackets:

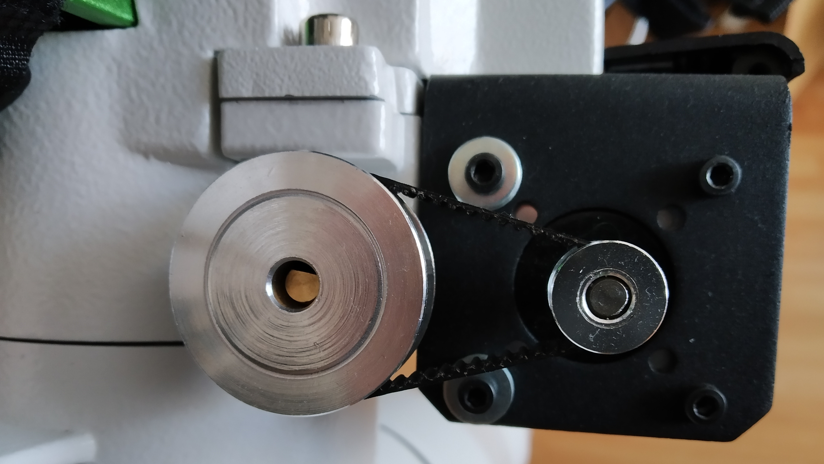
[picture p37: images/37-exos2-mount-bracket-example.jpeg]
EXOS2 mount with factory bracket mounting

*Credits: [Phobos Astronomy](https://phobos-astronomy.netlify.app/)*

The EQ4 used in this build has **no such mounting points**, so brackets couldn't be bolted on directly. The workaround:

1. A **solid steel angle** was custom-made at a local weld shop, sized to bear the motor's weight.
2. The angle was ground to fit the Dec axis, then drilled to match the screw pattern (washers recommended if hole alignment isn't perfect).
3. The modified steel angle was welded to the motor bracket. This was repeated for **both the RA and Dec axes**.

### Belt and pulley fitment

Per the [Configuration](#step-6-firmware-configuration) step, this build uses a **5:1** gear ratio: a 60-tooth GT2 pulley on the worm shaft and a 12-tooth GT2 pulley on the motor. See the [OnStep Drive Design wiki](https://onstep.groups.io/g/main/wiki/16264) for guidance on choosing pulleys and belts for your own ratio.

An open-loop belt was tried first (cut to length and joined with super glue) since the correct closed-loop length wasn't known in advance — this didn't hold up, but it confirmed the needed belt length. A **180mm closed-loop GT2 belt** was ordered afterward.

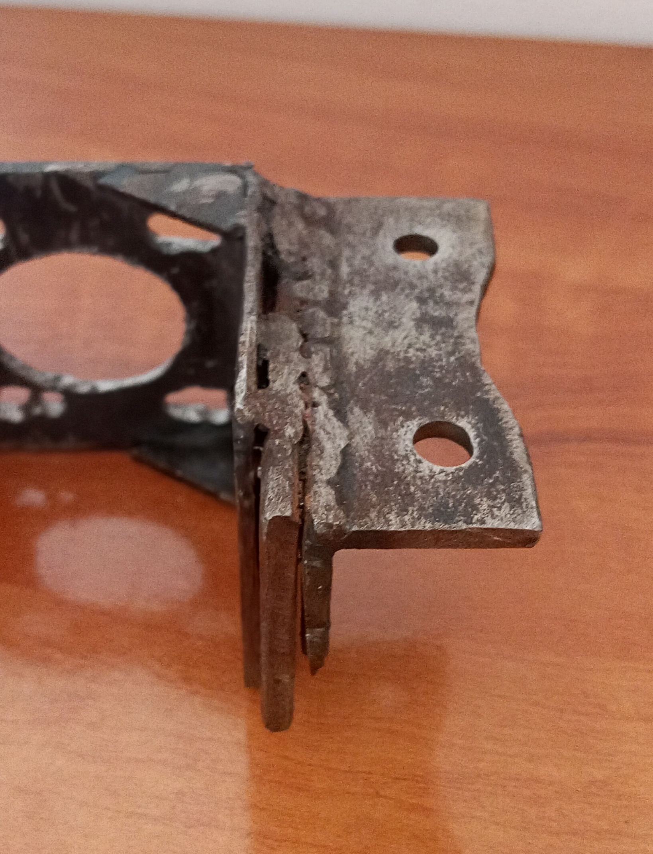
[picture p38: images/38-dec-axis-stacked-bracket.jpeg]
Bracket and pulleys stacked together


The belt ended up **4mm too long** for the pulley spacing; a 4mm spacer plate was added between the steel angle and the bracket to compensate.

The bracket holes were also enlarged into **oblong slots**, allowing the motor to slide and adjust belt tension:

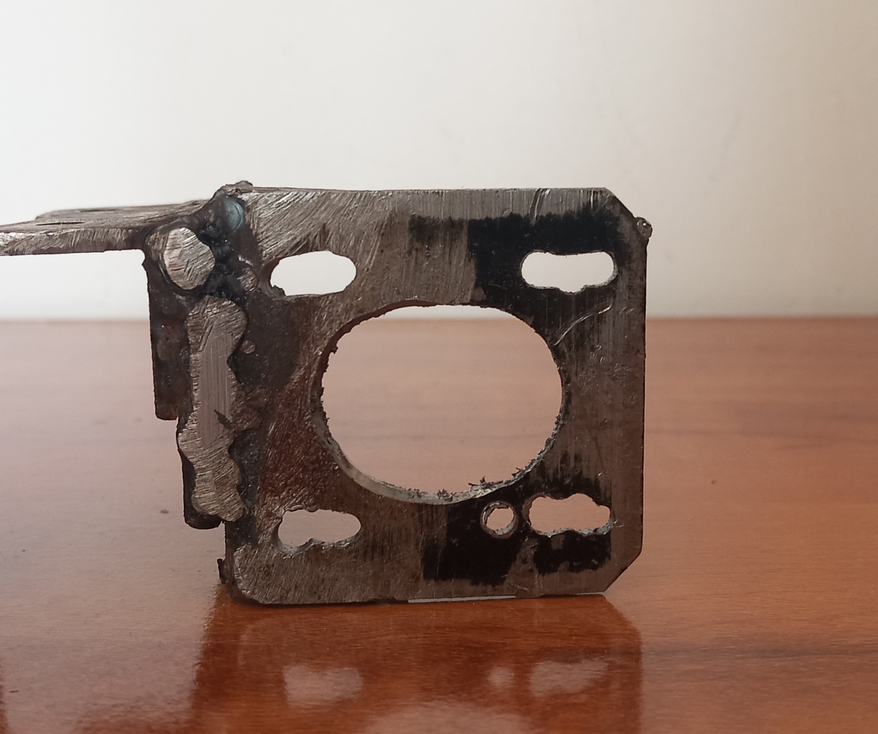
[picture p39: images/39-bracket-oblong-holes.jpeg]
Bracket with enlarged oblong holes


Final assembled Dec axis:

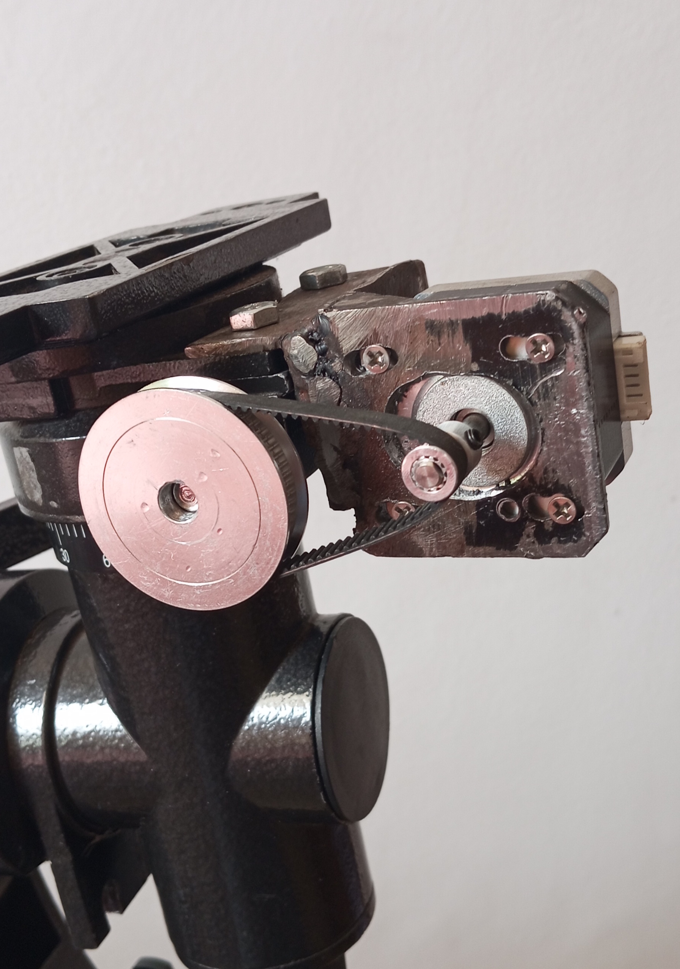
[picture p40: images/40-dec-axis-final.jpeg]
Finished Dec axis assembly


The same process was repeated for the RA axis.

## Safety Notes

- This build involves mains-adjacent DC power (12V @ up to 5A) and exposed PCB traces. Always double-check polarity and use a multimeter in continuity mode before powering on a new circuit for the first time.
- Set Vref **before** connecting a motor — an incorrectly set or unset Vref can damage the driver or motor.
- Never hot-plug motor connectors while the driver is powered.
- Handle the worm shaft and gear tension carefully — over-tightening can strip the wheel or bind the axis motor.

## Credits

- [**hjd1964**](https://github.com/hjd1964) — OnStepX firmware and plugin repositories
- [**Khalid Baheyeldin**](https://www.progressiveautomations.com/) — OnStep Configuration Generator
- [**Phobos Astronomy**](https://phobos-astronomy.netlify.app/) — EXOS2 bracket reference photo
- [OnStep community wiki](https://onstep.groups.io/g/main/wiki/3860) — general OnStep documentation

## Additional Photos & Videos

More photos and testing videos (breadboard testing, PCB assembly, and mount tracking tests) are available here:

📁 **[Google Drive — Photos & Videos](https://tinyurl.com/42mazz7c)

## Status / Next Steps

Both axes are wired, mechanically mounted, and configured. Remaining work / not yet documented here:
- End-to-end GoTo accuracy testing (polar alignment + star-based accuracy check).
- Final photos and video of the fully assembled mount in operation.

---

**Hardware used in this build:** EQ4 mount · ESP32 · DRV8825 · NEMA17 steppers · Custom KiCad PCB · OnStepX 10.24

## Note

This project uses v10.24 of OnStepX. All the changes mentioned above are present in files provided.

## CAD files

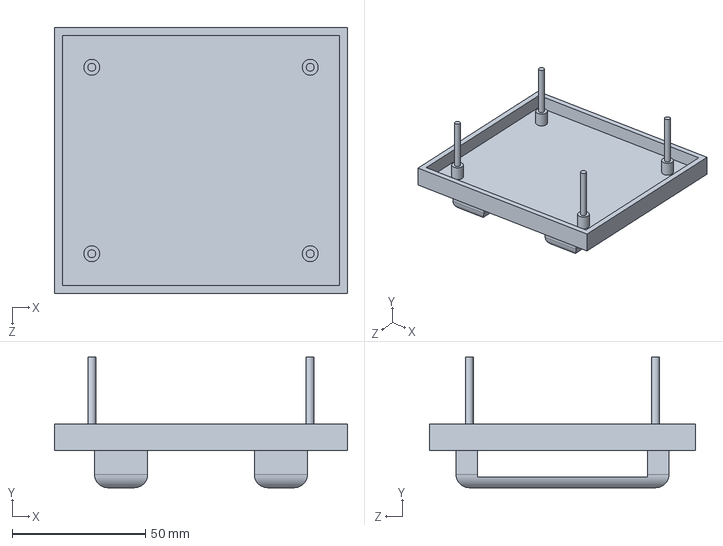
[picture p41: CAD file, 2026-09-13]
Case/CAD Files/Part1.SLDPRT
110.0 x 49.0 x 100.0 mm

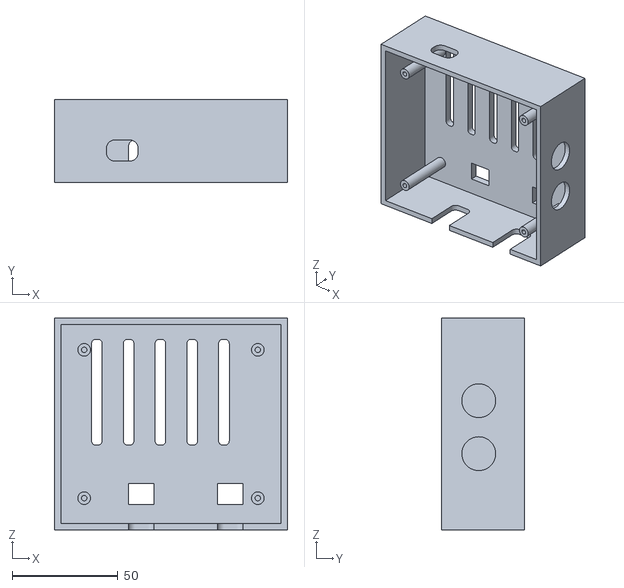
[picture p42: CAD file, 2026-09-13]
Case/Stl Files/topfinal.STL
110.0 x 39.0 x 100.0

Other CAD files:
Case/CAD Files/top.SLDPRT
Case/Stl Files/basefinal.STL

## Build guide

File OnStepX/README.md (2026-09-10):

OnStepX Telescope Controller
===========================

# What is OnStepX?
OnStepX is the advanced version of the OnStep computerized telescope controller with support for interfacing with/controlling a variety of motor drivers (and so motors) including Step/Dir, ODrive, and Servo (a combination of encoder and DC motor or Stepper motor) types.

It supports:
* Telescope Mount control (Alt/Azm and Equatorial GEM/Fork.)  Optional support for Eq mounts with Tangent Arm Declination.  Usually the Goto capability is enabled, but that's optional as well for those who just want basic mount control.
* Telescope Rotator control (including Alt/Azm de-rotation.)
* Telescope Focuser control (up to 6 focusers so it can handle collimation as well as focusing.)
* Telescope Accessory control (combination of up to 8 dew-heaters, switches, analog PWM.)

# Features
OnStepX supports a wide variety of connection options.  Several serial
"command channels" can be utilized. One of the these is normally devoted to a USB
connection and for the other(s) choose from the following:

* Bluetooth
* ESP8266 WiFi
* Arduino M0/Ethernet Shield
* Even another USB port or RS232 serial isn't very difficult to add.

In the case of running OnStepX on an ESP32 it can provide its own Bluetooth or WiFi IP command channels without additional hardware by simply activating the feature in OnStepX.

Other software in the OnStep ecosystem include:

* an [ASCOM](http://ascom-standards.org/) driver (with IP and Serial support),
* an Android App useable over WiFi or Bluetooth equipped Phones/Tablets,
* a "built-in" website (on the Ethernet and/or WiFi device),
* a full planetarium program that controls all features ([Sky Planetarium](http://stellarjourney.com/index.php?r=site/software_sky)).

OnStep is compatible with the LX200 protocol. This means it can be controlled
from other planetarium software, like: Sky Safari, CdC (even without ASCOM),
Stellarium, etc.

There are also [INDI](http://www.indilib.org/about.html) drivers so it can be used from Linux, with CdC or KStars.

# Documentation
Detailed documentation, including the full set of features, detailed designs for
PCBs, instructions on how to build a controller, how to configure the firmware
for your particular mount, can all be found the [OnStep Group Wiki](https://groups.io/g/onstep/wiki/home).

# Change Log
All the changes are tracking in git, and a detailed list can be accessed using the
following git command:
 
git log --date=short --pretty=format:"%h %ad %<(20)%an %<(150,trunc)%s"

# Support
Questions and discussion should be on the mailing list (also accessible via the
web) at the [OnStep Group](https://groups.io/g/onstep/).

# License
OnStep is open source free software, licensed under the GPL.

See [LICENSE.txt](./LICENSE.txt) file.

# Author
[Howard Dutton](http://www.stellarjourney.com)

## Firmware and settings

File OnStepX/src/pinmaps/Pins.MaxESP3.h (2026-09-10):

// -------------------------------------------------------------------------------------------------
// Pin map for OnStep MaxESP Version 3.x (ESP32S)
#pragma once

#if defined(ESP32)

// Serial0: RX Pin GPIO3, TX Pin GPIO1 (to USB serial adapter)
// Serial1: RX1 Pin GPIO10, TX1 Pin GPIO9 (on SPI Flash pins, must be moved to be used)
// Serial2: RX2 Pin GPIO16, TX2 Pin GPIO17

#if SERIAL_A_BAUD_DEFAULT != OFF
  #define SERIAL_A              Serial
#endif
#if SERIAL_B_BAUD_DEFAULT != OFF
  #define SERIAL_B              Serial2
#endif

// Use the following settings for any TMC UART driver (TMC2209) that may be present
#if defined(STEP_DIR_TMC_UART_PRESENT) || defined(SERVO_TMC2209_PRESENT)
  #if defined(SERIAL_TMC_HARDWARE_UART)
    #define SERIAL_TMC          Serial1          // Use a single hardware serial port to up to four drivers
    #define SERIAL_TMC_BAUD     460800           // Baud rate
    #define SERIAL_TMC_RX       39               // Recieving data
    #define SERIAL_TMC_TX       23               // Transmit data
    #define SERIAL_TMC_ADDRESS_MAP(x) ((x==4)?2 : x) // Axis1(0) is 0, Axis2(1) is 1, Axis3(2) is 2, Axis4(3) is 3, Axis5(4) is 2
  #endif
#endif

// Specify the ESP32 I2C pins
#define I2C_SDA_PIN             21
#define I2C_SCL_PIN             22

// The multi-purpose pins (Aux3..Aux8 can be analog pwm/dac if supported)
#define AUX2_PIN                4                // ESP8266 RST control, or MISO for Axis1&2, or Axis4 EN support
#define AUX3_PIN                21               // Home SW for Axis1, or I2C SDA
#define AUX4_PIN                22               // Home SW for Axis2, or I2C SCL
#define AUX7_PIN                39               // Limit SW, PPS, etc.
#define AUX8_PIN                25               // 1-Wire, Status LED, Reticle LED, Tone, etc.

// Misc. pins
#ifndef ONE_WIRE_PIN
  #define ONE_WIRE_PIN          AUX8_PIN         // Default Pin for OneWire bus
#endif
#define ADDON_GPIO0_PIN         26               // ESP8266 GPIO0 (Dir2)
#ifndef ADDON_RESET_PIN
  #define ADDON_RESET_PIN       AUX2_PIN         // ESP8266 RST
#endif

// The PEC index sense is a logic level input, resets the PEC index on rising edge then waits for 60 seconds before allowing another reset
#ifndef PEC_SENSE_PIN
  #define PEC_SENSE_PIN         36               // [input only 36] PEC Sense, analog (A0) or digital (GPIO36)
#endif

// The status LED is a two wire jumper with a 2k resistor in series to limit the current to the LED
#ifndef STATUS_LED_PIN
  #define STATUS_LED_PIN        AUX8_PIN         // Default LED Cathode (-)
#endif
#define MOUNT_LED_PIN           STATUS_LED_PIN   // Default LED Cathode (-)
#ifndef RETICLE_LED_PIN 
  #define RETICLE_LED_PIN       STATUS_LED_PIN   // Default LED Cathode (-)
#endif

// For a piezo buzzer
#ifndef STATUS_BUZZER_PIN
  #define STATUS_BUZZER_PIN     AUX8_PIN        // Tone
#endif

// The PPS pin is a 3.3V logic input, OnStep measures time between rising edges and adjusts the internal sidereal clock frequency
#ifndef PPS_SENSE_PIN
  #define PPS_SENSE_PIN         AUX7_PIN         // PPS time source, GPS for example
#endif

// The limit switch sense is a logic level input normally pull high (2k resistor,) shorted to ground it stops gotos/tracking
#ifndef LIMIT_SENSE_PIN
  #define LIMIT_SENSE_PIN       AUX7_PIN
#endif

#define SHARED_DIRECTION_PINS                    // Hint that the direction pins are shared
#define SHARED_ENABLE_PIN       12               // Hint that the enable pins are shared

// Axis1 RA/Azm step/dir driver
#define AXIS1_ENABLE_PIN        SHARED           // [must be low at boot 12]
#define AXIS1_M0_PIN            13               // SPI MOSI
#define AXIS1_M1_PIN            14               // SPI SCK
#define AXIS1_M2_PIN            23               // SPI CS (UART TX)
#if AXIS4_POWER_DOWN != ON
  #define AXIS1_M3_PIN          AUX2_PIN         // SPI MISO (UART RX)
#endif
#define AXIS1_STEP_PIN          18
#define AXIS1_DIR_PIN           0                // [must be high at boot 0]
#ifndef AXIS1_SENSE_HOME_PIN
  #define AXIS1_SENSE_HOME_PIN  AUX3_PIN
#endif

// Axis2 Dec/Alt step/dir driver
#define AXIS2_ENABLE_PIN        SHARED
#define AXIS2_M0_PIN            13               // SPI MOSI
#define AXIS2_M1_PIN            14               // SPI SCK
#define AXIS2_M2_PIN            5                // SPI CS (UART TX)
#if AXIS4_POWER_DOWN != ON
  #define AXIS2_M3_PIN          AUX2_PIN         // SPI MISO (UART RX)
#endif
#define AXIS2_STEP_PIN          27
#define AXIS2_DIR_PIN           26
#ifndef AXIS2_SENSE_HOME_PIN
  #define AXIS2_SENSE_HOME_PIN  AUX4_PIN
#endif
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

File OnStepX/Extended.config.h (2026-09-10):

/* ---------------------------------------------------------------------------------------------------------------------------------
 * Extended configuration for OnStepX INFREQUENTLY USED options
 *
 *          For more information on setting OnStep up see http://www.stellarjourney.com/index.php?r=site/equipment_onstep 
 *                      and join the OnStep Groups.io at https://groups.io/g/onstep
 * 
 *           *** Read the compiler warnings and errors, they are there to help guard against invalid configurations ***
 *
 * ---------------------------------------------------------------------------------------------------------------------------------
 * ADJUST THE FOLLOWING TO CONFIGURE YOUR CONTROLLER FEATURES ----------------------------------------------------------------------
 * <-Req'd = always must set, <-Often = usually must set, Option = optional, Adjust = adjust as req'd, Infreq = infrequently changed
*/
//      Parameter Name              Value   Default  Notes                                                                      Hint

// =================================================================================================================================
// CONTROLLER ======================================================================================================================

// DEBUG ---------------------------------------------------------------------------------------------------------------------------
// Enables additional debugging and/or status messages on the specified SERIAL_DEBUG port (be sure to disable when done!)
// Note: The SERIAL_DEBUG port is often (almost always) attached to the same SERIAL_A port so it cannot be used for normal
//       LX200 protocol communications.  If this is the case set both to the same (faster) baud rate specified below.
#define DEBUG                         ON //    OFF, Use ON for background error messages only, use VERBOSE for all           Infreq
                                          //         error and status messages, use CONSOLE for VT100 debug console,
                                          //         or use PROFILER for VT100 task profiler.
#define DEBUG_SERVO                   OFF //    OFF, n. Where n=1 to 9 as the designated axis for logging servo activity.     Option
#define DEBUG_ECHO_COMMANDS           OFF //    OFF, Use ON or ERRORS_ONLY to log commands to the debug serial port.          Option
#define SERIAL_DEBUG               Serial // Serial, Use any available h/w serial port. Serial1 or Serial2, etc.              Option
#define SERIAL_DEBUG_BAUD          230400 // 230400, n. Where n=9600,19200,57600,115200,230400,460800 (common baud rates.)    Option

// NON-VOLATILE STORAGE ------------------------------------------------------------------------------------------------------------
#define NV_WIPE                       OFF //         OFF, Causes the defaults to be written back into NV (FLASH,EEPROM,etc.)  Infreq
                                          //              ***     IMPORTANT: ENABLE THIS OPTION THEN UPLOAD, WAIT A MINUTE    ***
// Warning --->                           //              ***     OR TWO THEN SET THIS OPTION TO OFF AND UPLOAD AGAIN.        ***
                                          //              ***     LEAVING THIS OPTION ENABLED CAN CAUSE EXCESSIVE NV          ***
                                          //              ***     WEAR AND DAMAGE THE MICROCONTROLLER NV SUBSYSTEM !!!        ***

// ---------------------------------------------------------------------------------------------------------------------------------
#define SERIAL_IP_MODE WIFI_ACCESS_POINT
#define WEB_SERVER ON

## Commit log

2026-09-13 Add KICAD project files
    [onstep.kicad_pcb, onstep.kicad_sch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]
2026-09-13 PCB Case Files
    [Part1.SLDPRT, basefinal.STL, top.SLDPRT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]
